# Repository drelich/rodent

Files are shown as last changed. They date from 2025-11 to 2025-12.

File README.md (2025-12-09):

# rodent (Rod Trident)
## Voron Trident with Z rods.

I decided to build a [Voron Trident](https://github.com/VoronDesign/Voron-Trident/) with the scrap materials I have at home. The idea was to spend zero cash (ideally) or as little as possible on this build. I do have the Voron 0.2 already but with its 100x100 build plate, it is not much of a use if I wanted to print cool models to display in my flat. Still, this tiny fella will do me fine for printing most of the parts (the big ones will have to wait until this project is somewhat more complete).

This printer will be my test-bed for something I am thinking of doing: a tool changer. Yay!

### Some notes
To prevent the bed assembly from wobbling/rotating, I've opted for rigid mounts on the front left and right bed Z carriages. The rear Z axis is left intact/original. 

Printer measurements:
- width: 470 mm
- depth: 490 mm
- height: 630 mm (including feet that create space for electronics, and some extra extrusion at the top for I have some other plans with those in the near future).

For now, the printer is not enclosed but it's definitely in the stars.

The print volume (roughly):
- X: 300 mm
- Y: 300 mm  
- Z: 250 mm

using 350 mm smooth rods (10 mm diameter), LM10UU bearings. For the Y axis, I am using old MGN12 linear rails @ 350mm length. The extra travel will be used for tool head swaps and nozzle cleaning. The X axis is handled by an old MGN12 linear rail, that's about 350 mm long.

Screenshots from my Fusion 360 files:
1. Z-axis rear (simple enough, I did have to keep in mind the 2020 profile offset caused by the A/B motor mounts)

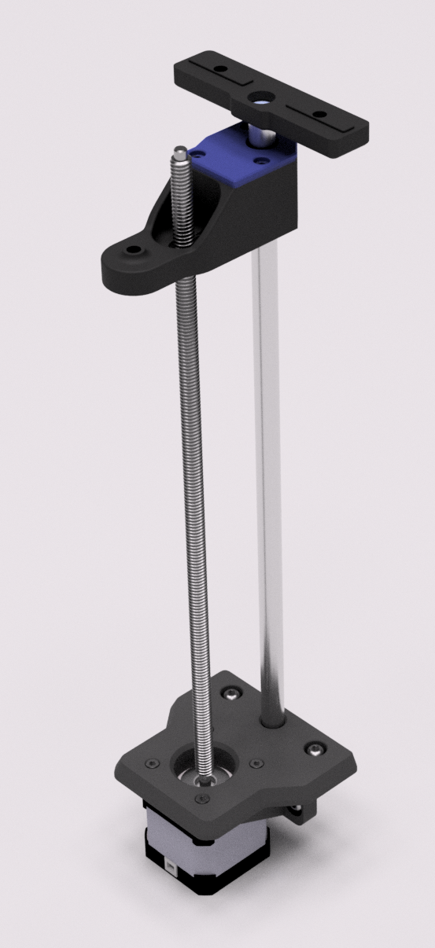
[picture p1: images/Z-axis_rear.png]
Z-axis_rear Z-axis rear


2. Z-axis for the sides - modelled left side but right side is easily done by just mirroring the STL files by X axis in your slicer

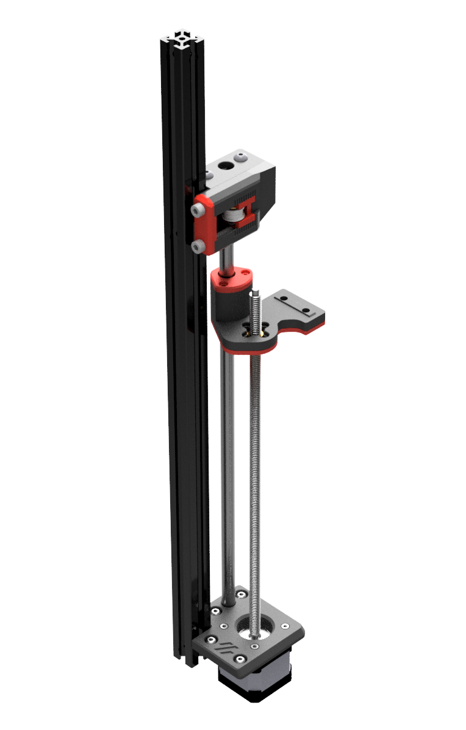
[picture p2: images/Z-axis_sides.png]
Z-axis_sides Z-axis for the sides - modelled left side but right side is easily done by just mirroring the STL files by X axis in your slicer


Detailed views of the front Z axis assembly:

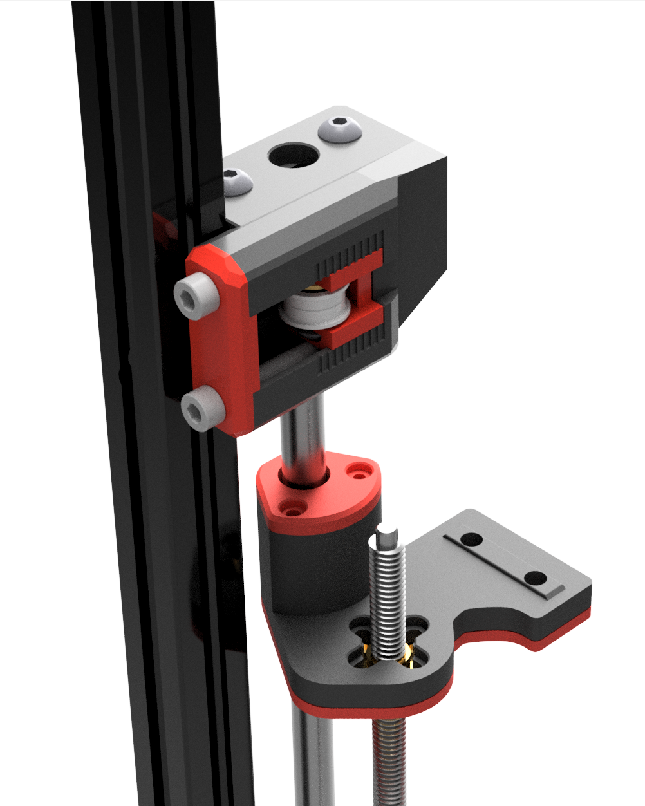
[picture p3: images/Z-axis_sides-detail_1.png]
Z-axis_sides-detail_1 Detail view 1 of the front Z axis assembly

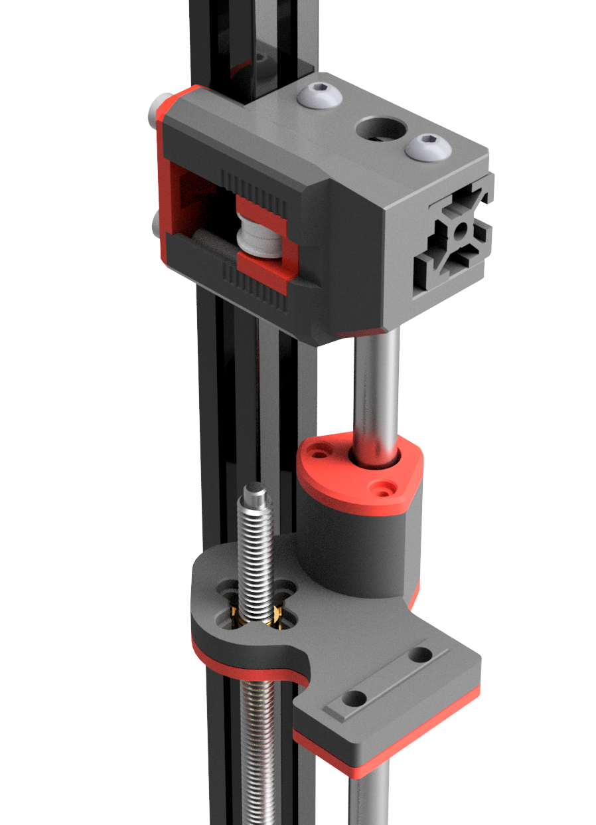
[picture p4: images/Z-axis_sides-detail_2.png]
Z-axis_sides-detail_2 Detail view 2 of the front Z axis assembly

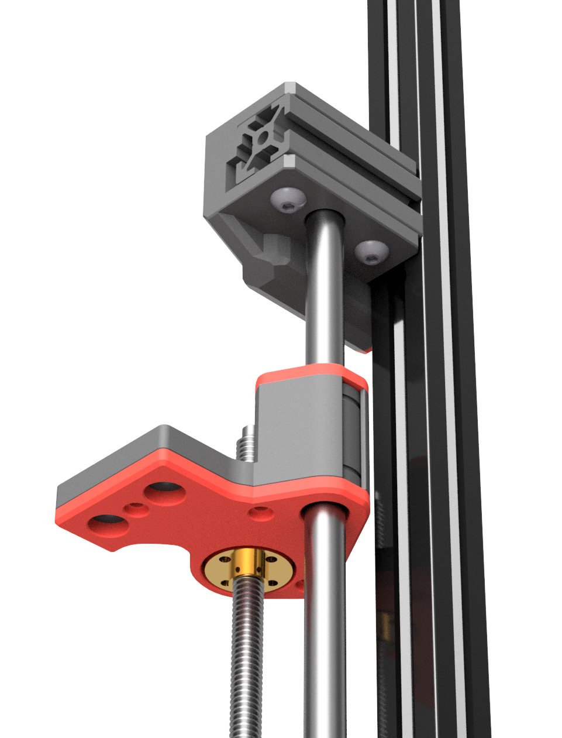
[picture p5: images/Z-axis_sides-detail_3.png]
Z-axis_sides-detail_3 Detail view 3 of the front Z axis assembly


And a close-up photo of the assembly:

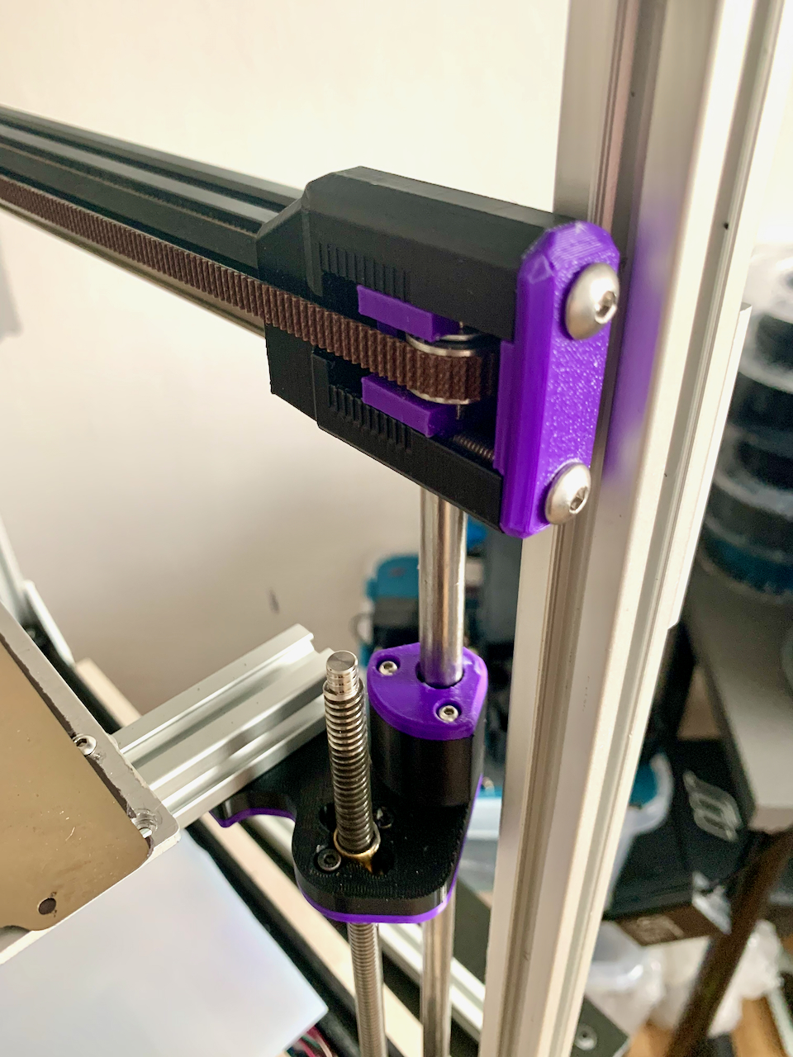
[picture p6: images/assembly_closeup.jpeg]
assembly_closeup Close-up of the assembly


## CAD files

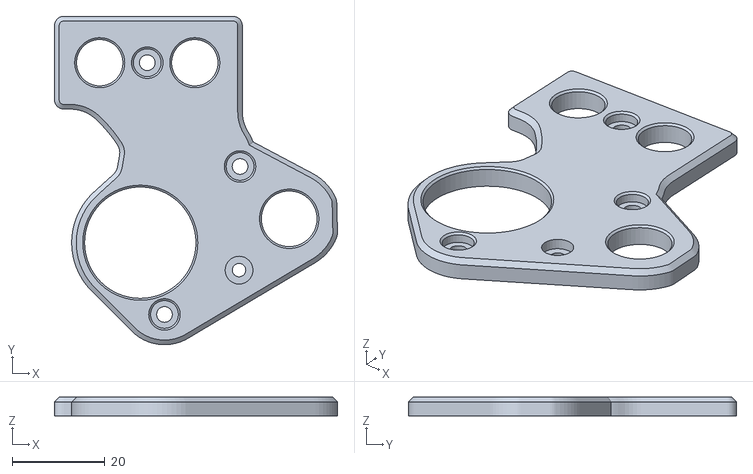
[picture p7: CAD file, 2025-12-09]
STL/Z_Carriage_Side-Bottom_Cover_1x_plus_1x-mirror-x.stl
61.0 x 70.8 x 4.00

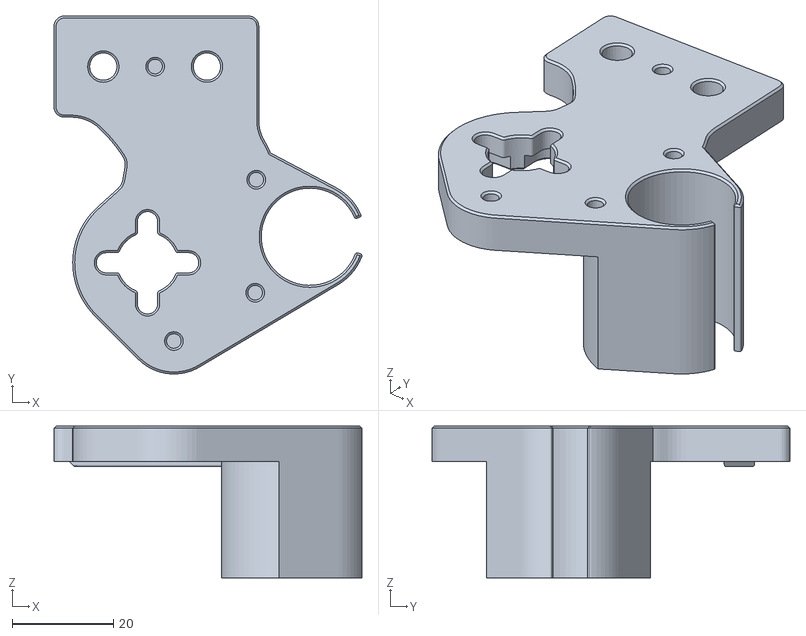
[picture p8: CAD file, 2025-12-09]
STL/Z_Carriage_Side_1x_plus_1x_mirror-x.stl
60.9 x 70.8 x 30.0

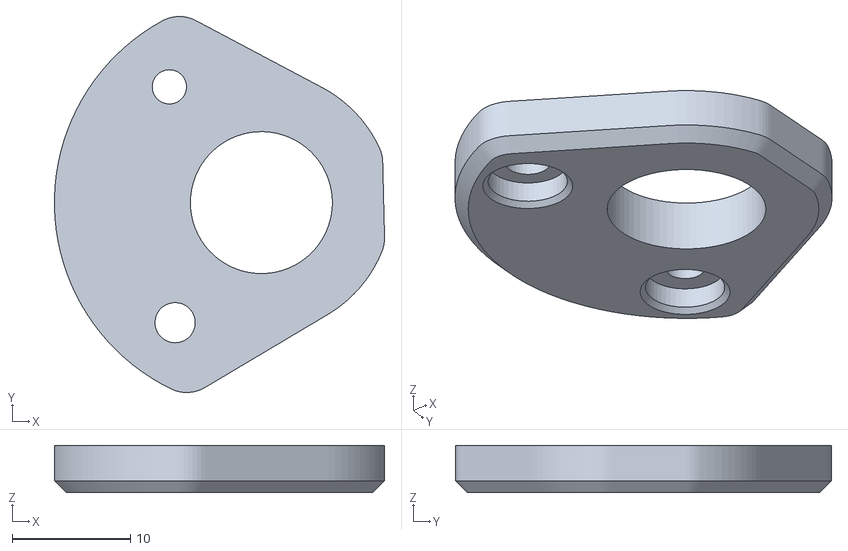
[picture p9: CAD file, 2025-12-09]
STL/Z_Carriage_Side-Top_Cover_1x_plus_1x_mirror-x.stl
27.9 x 31.8 x 4.00

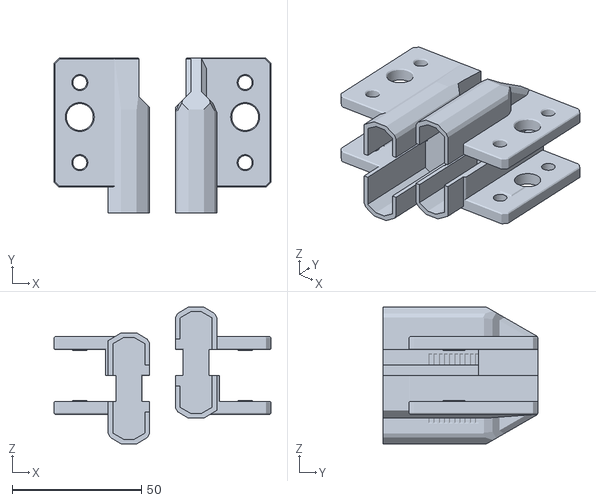
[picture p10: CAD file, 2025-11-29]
STL/BFI for Rodent.stl
84.0 x 60.0 x 53.0

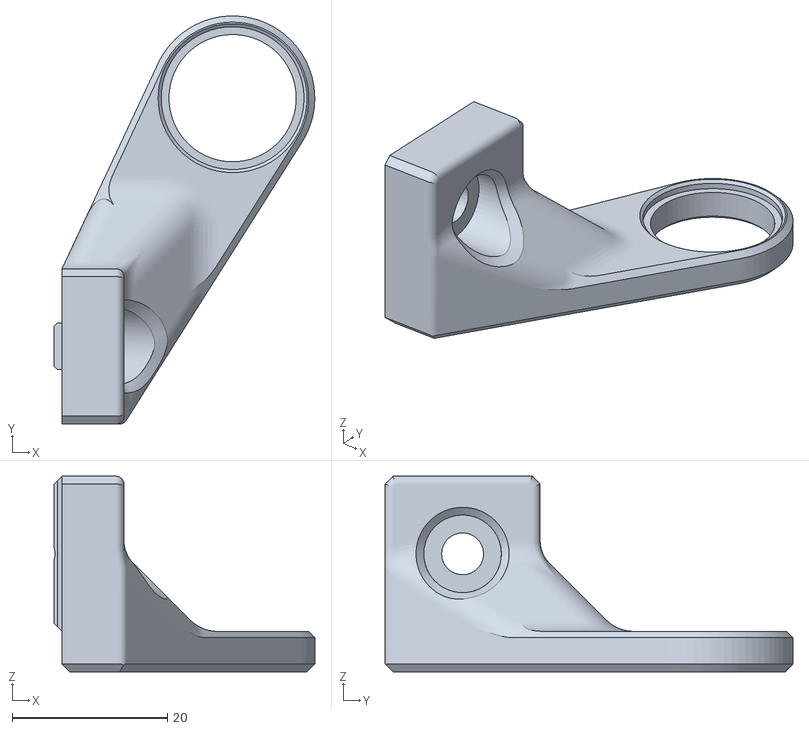
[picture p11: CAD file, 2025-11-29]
STL/Front_Z_Axis_Anchor_x1_plus_1x_mirror.stl
33.6 x 52.6 x 25.2

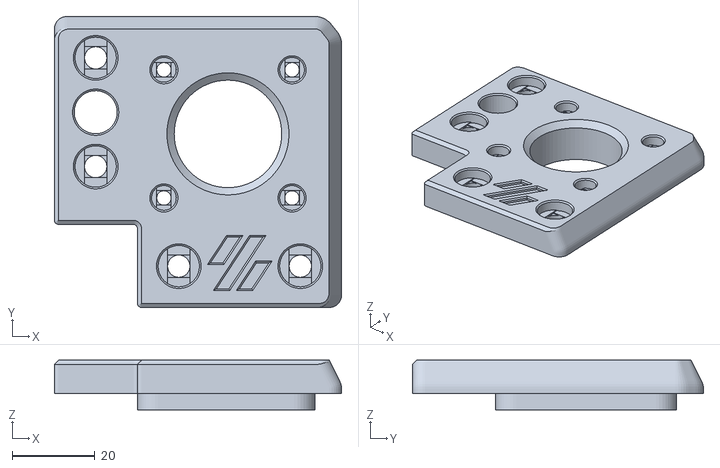
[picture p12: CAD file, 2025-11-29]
STL/z_stepper_left.stl
69.5 x 70.4 x 12.0

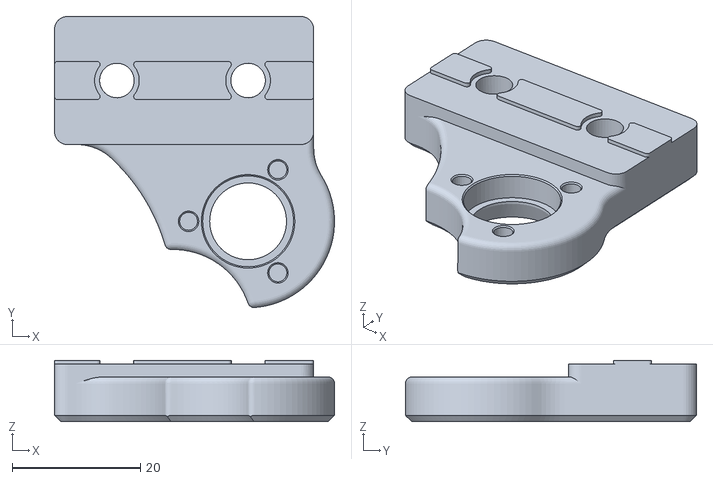
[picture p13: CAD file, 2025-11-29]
STL/Z_bed_left_x1_plus_1x_mirror.stl
43.7 x 45.5 x 9.60

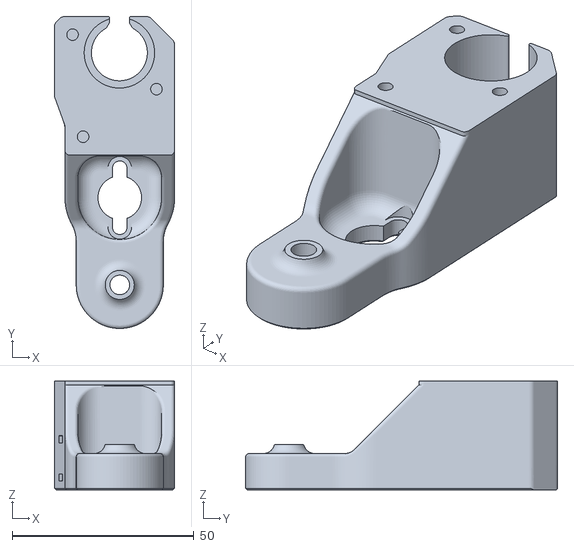
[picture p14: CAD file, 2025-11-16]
STL/Z_Carriage_Rear_3-Hole_Generic.stl
33.1 x 85.9 x 29.9

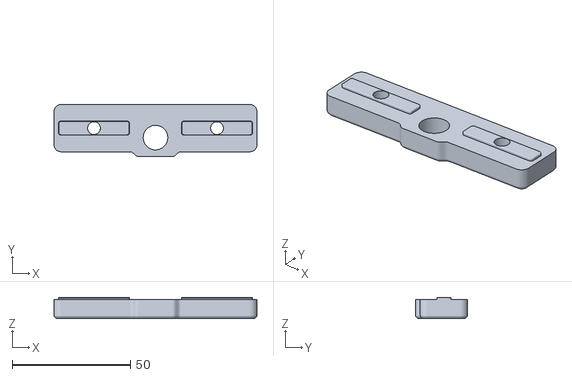
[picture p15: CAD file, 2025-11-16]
STL/Z_Rod_Top_Mount-Back.stl
85.8 x 22.0 x 9.00

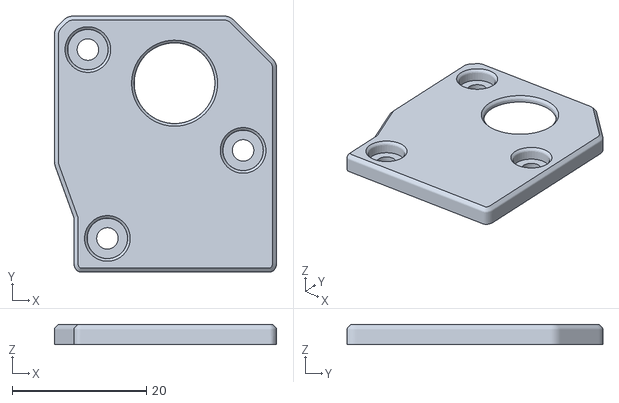
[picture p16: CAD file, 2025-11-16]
STL/Z_Carriage_Rear_Top_Cover.stl
33.1 x 38.1 x 3.00

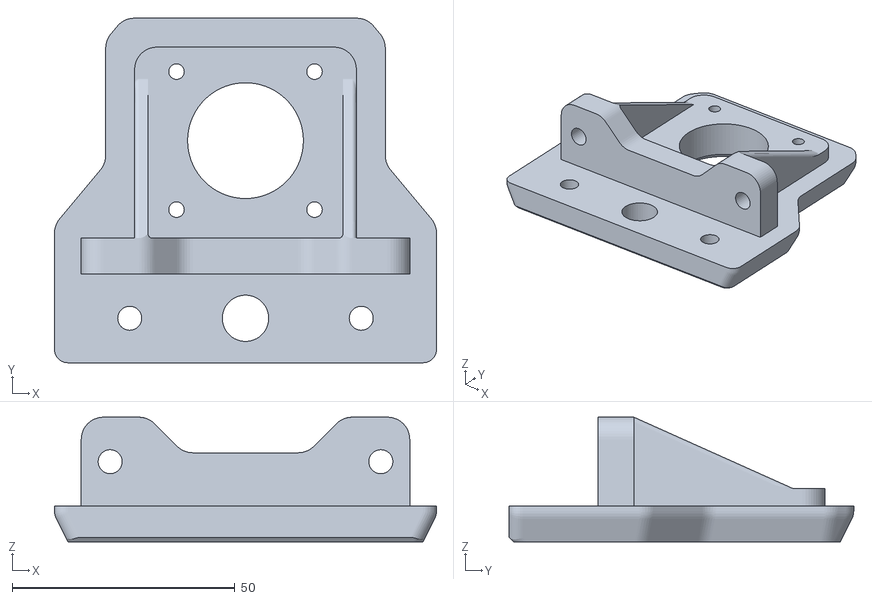
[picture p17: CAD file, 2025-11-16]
STL/Z_Motor_Mount_Back.stl
85.8 x 77.4 x 28.0

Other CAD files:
STL/z_stepper_right.stl

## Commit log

2025-11-16 Initial commit
    Updated README file, added Z axis mods in their current state.
    [Z_Carriage_Rear_3-Hole_Generic.stl, Z_Carriage_Rear_Top_Cover.stl, Z_Carriage_Side-Bottom_Cover_1x_plus_1x-mirror-x.stl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]
2025-11-29 Update README.md with printer specifications and Z-axis details, update STL files
    [BFI for Rodent.stl, Front_Z_Axis_Anchor_x1_plus_1x_mirror.stl, Z_Carriage_Side-Bottom_Cover_1x_plus_1x-mirror-x.stl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]
2025-11-29 Update README.md with additional Z-axis anchor notes
2025-11-29 Add close-up photo of Z-axis assembly to README.md
2025-11-29 Update Z-axis smooth rod length specification from 300mm to 350mm in README.md
2025-12-09 Final version of rod mod, with fixed bed front Z carriage mounts
    [Z_Carriage_Side-Bottom_Cover_1x_plus_1x-mirror-x.stl, Z_Carriage_Side-Top_Cover_1x_plus_1x_mirror-x.stl, Z_Carriage_Side_1x_plus_1x_mirror-x.stl]
2025-12-09 fix: proper spacing for the leadscrew nut to be able to move around a bit
    [Z_Carriage_Side-Bottom_Cover_1x_plus_1x-mirror-x.stl]
